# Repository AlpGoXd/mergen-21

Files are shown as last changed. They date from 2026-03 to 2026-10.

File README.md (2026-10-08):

<p align="center">
  Mergen-21 Logo
</p>

# Mergen-21: Low-Cost 21 cm Hydrogen Line Radio Telescope



A radio telescope I built for my EE401 graduation project at Ozyegin University. It listens at 1420.405 MHz (the hydrogen line), and I used it to detect hydrogen emission from the Milky Way at several pointings. Mapping its rotation is future work.

**Science goal (future work):** a Galactic rotation curve via the tangent-point method, observed from Istanbul, Turkey. The released results are first-light hydrogen-line detections with pointing dependence (south/east/west); velocity/rotation-curve analysis is not yet complete (see "Reproducing the paper" below).

---

## System Overview

RF System Block Diagram

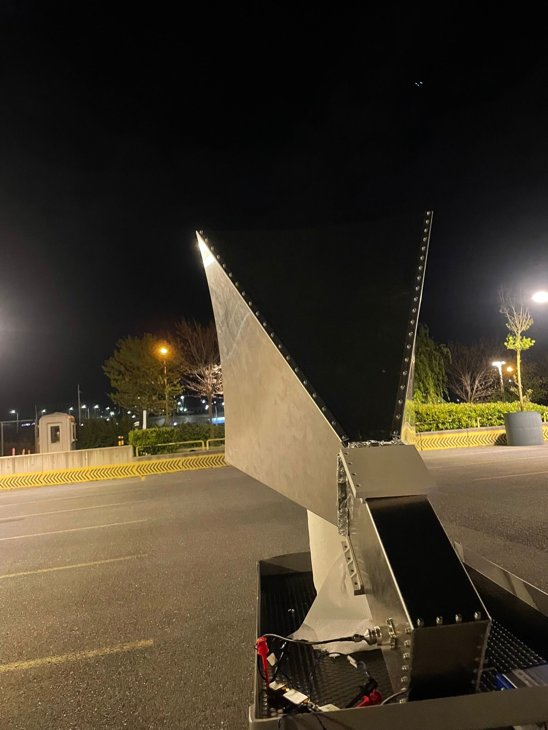
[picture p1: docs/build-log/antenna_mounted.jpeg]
Antenna mounted for first-light observations


### Antenna
- **Type:** Pyramidal horn, 1.5 mm aluminum sheet, laser-cut & bolted (M3, see ASSEMBLY.md)
- **Design frequency:** 1420.405 MHz (HI 21 cm line)
- **Measured S11:** better than −30 dB from 1410 to 1440 MHz (ZNB8, 10 MHz grid; −41.8 dB at the 1420.000 MHz sample, so the null depth is not resolved)
- **Simulated S11 (CST Studio Suite):** ideal model −19.7 dB at 1420 MHz (minimum −30.7 dB at 1396 MHz); worst-case assembly model −21.8 dB at 1420 MHz (minimum −23.1 dB at 1410 MHz)
- **Directivity:** 16.9 dBi at 1.42 GHz
- **3 dB beamwidth (simulated):** 25.2° (H-plane), 22.0° (E-plane)

### RF Chain
| Stage | Component | Function | Gain, VNA / datasheet (dB) | NF (dB) | OIP3 (dBm) |
|---|---|---|---|---|---|
| 1 | ZX60-P162LN+ | LNA | 19.24 / 19.87 | 0.7 | +29.8 |
| 2 | ZX75BP-1450-S+ | Bandpass filter (datasheet: 1 dB passband 1254–1625 MHz, 3 dB passband 1230–1645 MHz; 0.79 dB loss at 1420.4 MHz) | −1.73 / −0.79 | 0.8 | N/A |
| 3 | ZX60-V63+ | Second amplifier | 20.24 / 20.82 | 3.7 | +32.2 |
| **Cascade** | **LNA + BPF + Amp** | | **39.52 (VNA, interpolated; samples 39.66 dB at 1402.51 MHz and 39.32 dB at 1445.01 MHz)** | **1.5 (meas., cable-corrected)** | **+29.5 (meas.)** |

Gains are |S21| at 1420.405 MHz, computed by `software/analysis/stage_gains.py` (output `software/analysis/outputs/stage_gains.csv`). The measured stages sum to 37.75 dB, 1.8 dB below the measured cascade; the single-stage files are not de-embedded and the filter file includes test adapters and cables, so the cascade file is the reference for the chain gain.

### Backend
- **SDR:** ADALM-PLUTO
- **Software:** GNU Radio for signal acquisition
- **Analysis:** Python (NumPy, SciPy, Matplotlib, Astropy)

Here's what the GNU Radio receiver flowgraph looks like:

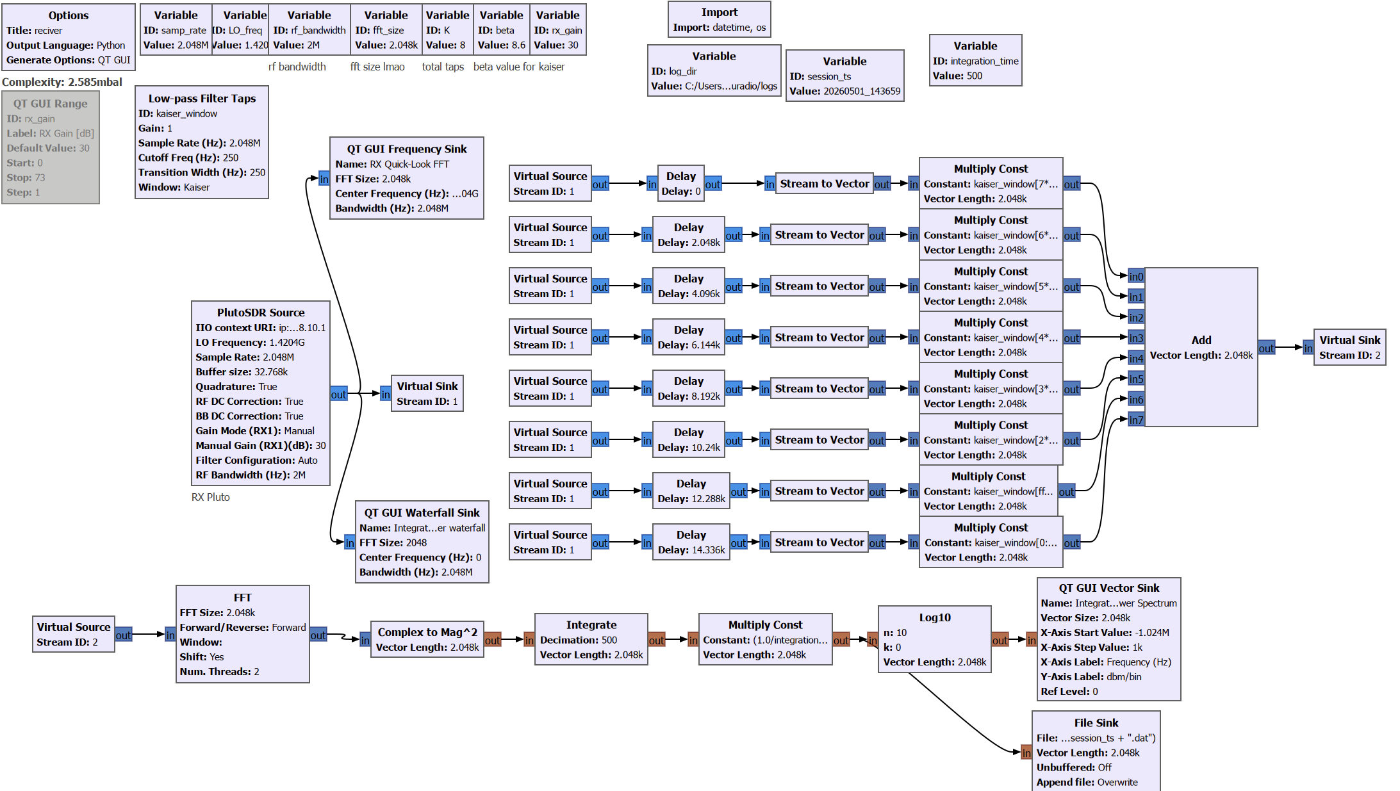
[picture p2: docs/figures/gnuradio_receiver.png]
GNU Radio receiver flowgraph


### Mechanical
- Horn antenna from laser-cut aluminum sheet metal
- Waveguide-to-coax transition with N-type connector
- A 3D-printed tripod adapter was designed (files in `hardware/antenna/3d-print/`) but the mount did not work out in practice and wasn't used for observations. While observing, the horn rested on its narrow (80 mm) wall with the N-connector axis horizontal (E-plane horizontal), not hand-held.

---

## Project Status

| Component | Status | Notes |
|---|---|---|
| Hardware (antenna, RF chain, LDO) | Complete | Fully characterized; measurement data available |
| Power supply board | Complete | Gerbers ready; BOM in `hardware/ldo-regulator/bom.pdf` |
| Simulations (CST, AWR) | Complete | Exported results in `hardware/simulation/` |
| Measurements (VNA, IP3, NF) | Complete | 39.5 +/- 0.5 dB gain, 1.5 dB NF (cable-corrected), OIP3 +29.5 dBm (cascade) |
| GNU Radio flowgraphs | Complete | `receiver.grc` (main) + `21cm synth/` test flowgraphs |
| Analysis software | Complete | `mergen21_hi_analysis.py` and `first_light_and_averaging.py` reproduce the manuscript's line fits and averaging-noise tables; see "Reproducing the paper" below and `software/analysis/outputs/VERIFICATION.md` |
| First-light observations | Complete | South/east/west pointings, 2026-04-29; data in `observations/data/`. Azimuth sweep and rotation-curve analysis are not part of the released results (see `docs/analysis/PROVENANCE_ADDENDUM.md`) |
| Open-source release | Released as v1.0-apm | Tagged release for the IEEE AP Magazine submission |

---

## Key Results

### RF Receiver
- **Cascade gain:** 39.5 dB +/- 0.5 dB (measured via ZNB8; the VNA cascade file has ~42.5 MHz point spacing and has no sample at 1420.405 MHz, the nearest points being 1402.50835 MHz and 1445.0083 MHz)
- **Cascade NF:** about 1.5 dB (1.54 dB, cable-corrected gain-method estimate: measured output noise density -133.46 dBm/Hz, +0.6 dB +/-0.2 dB estimated output-cable correction, minus the -173.9 dBm/Hz thermal floor, minus the 39.5 dB gain; add +/-0.5 dB from gain uncertainty). Friis-formula prediction: 0.81 dB with VNA stage gains (0.77 dB with datasheet gains). Design requirement: 0.96 dB.
- **Cascade OIP3:** +29.54 dBm, output-referred (−12 dBm total two-tone input, i.e. −15 dBm per tone; TOI spread 0.3 dB)
- Measurements traceable to R&S ZNB8 VNA & FSVA3044 spectrum analyzer

### Antenna
- **Measured S11:** better than −30 dB from 1410 to 1440 MHz (ZNB8, 10 MHz grid; −41.8 dB at the 1420.000 MHz sample, so the null depth is not resolved)
- **Simulated directivity:** 16.9 dBi
- **3 dB beamwidth (simulated):** 25.2° (H-plane), 22.0° (E-plane)
- Material: 1.5 mm aluminum sheet, laser-cut

---

## Repository Structure

```
mergen-21/
├── hardware/                    # All hardware (antenna, RF chain, power, sims)
│   ├── antenna/                 # Horn: CAD, drawings, DXF, STL, photos
│   ├── rf-chain/                # Component datasheets & S-parameters
│   ├── ldo-regulator/           # Dual LDO board (Altium, Gerbers, BOM, STEP)
│   └── simulation/              # CST antenna sims & AWR cascade analysis
├── measurements/                # Lab characterization data
│   ├── rf-chain/vna/            # VNA S-parameters (R&S ZNB8)
│   ├── rf-chain/ip3/            # IP3 / intermodulation
│   ├── rf-chain/nf/             # Noise figure
│   └── antenna/                 # Horn S11 & manufacturing notes
├── software/                    # Data acquisition & analysis
│   ├── gnuradio/                # GNU Radio flowgraphs (.grc) + synthesizer test flows
│   └── analysis/                # Python scripts (waterfall viewer, etc.)
├── observations/                # First-light data & plots (2026-04-29)
│   ├── data/                    # Raw spectra (.dat, NumPy float32): sample data included
│   └── plots/                   # Waterfall & sweep plots
└── docs/                        # Lab manuals, BOM, build log, diagrams
    ├── lab-manual-01-simulate.md  # Lab 1: EM sim + RF cascade analysis
    ├── lab-manual-02-build.md     # Lab 2: Fabrication & assembly
    ├── lab-manual-03-measure.md   # Lab 3: VNA, NF, IP3 characterization
    ├── lab-manual-04-observe.md   # Lab 4: GNU Radio observation & data analysis
    └── bom.md                     # Full BOM with distributor part numbers
```

## Quick Navigation

- **Try it without hardware?** → `python software/analysis/mergen21_waterfall_viewer.py` then load any `.dat` from `observations/data/`
- **Hardware files?** → [`hardware/`](hardware/): antenna CAD, RF chain, LDO, simulations
- **Measurement data?** → [`measurements/`](measurements/)
- **First-light data?** → [`observations/`](observations/): raw spectra + plots (2026-04-29)
- **Lab manuals?** → [`docs/`](docs/): four-phase curriculum (simulate, build, measure, observe)
- **BOM + costs?** → [`docs/bom.md`](docs/bom.md)
- **Running the receiver?** → [`software/gnuradio/`](software/gnuradio/): flowgraphs + setup
- **Build progress?** → [`docs/STATUS.md`](docs/STATUS.md)

---

## Quickstart: 5 minutes, no hardware required

```bash
git clone https://github.com/AlpGoXd/mergen-21.git
cd mergen-21
pip install -r software/requirements.txt
python software/analysis/mergen21_waterfall_viewer.py
```

In the viewer, click **Add...** and open any `.dat` file from `observations/data/`. Set X axis to **Velocity [km/s]** and click **Plot**. You will see two features. The narrow spike at the LO (0 kHz, 0 km/s on the velocity axis) is the band-center instrumental artifact, not hydrogen. The broad hump 80 to 190 kHz above the LO (about −16 to −36 km/s on the viewer's uncorrected topocentric axis) is the Galactic H I line.

No SDR, no antenna, no GNU Radio needed for this step. The viewer reads the recorded spectra directly.

---

## Getting Started

```bash
git clone https://github.com/AlpGoXd/mergen-21.git
cd mergen-21
pip install -r software/requirements.txt
```

**Dependencies:**
- GNU Radio 3.10+ with PlutoSDR block (gr-iio): only needed for live acquisition
- Python 3.11+: `numpy`, `scipy`, `pandas`, `matplotlib`, `astropy` (pinned in `software/requirements.txt`); the viewer also needs Tk (`python3-tk` on Debian/Ubuntu)

> CST, AWR, and Autodesk Inventor are only needed to re-run simulations or edit CAD. All exported results (S-parameters, STEP, Gerbers, PDFs) are already in the repo.

**Total system cost:** ~$413–$513 USD (see [`docs/bom.md`](docs/bom.md) for full breakdown).

---

## Observation Site

- **Location:** Istanbul, Turkey (~41.0°N, 29.0°E)
- **Target:** Galactic plane HI emission at various galactic longitudes
- **Method (future work):** tangent-point method for rotation curve extraction; not yet performed on the released data (needs frequency-axis verification, oscillator calibration, and pointing records not yet in place -- see `docs/analysis/PROVENANCE_ADDENDUM.md`)

---

## Reproducing the paper

All commands are run from the repository root, with `software/requirements.txt` installed. Each command regenerates one output; `--root` points at a checkout of this repository (defaults to the current directory) and `--outdir` selects where outputs are written.

| Command | Produces |
|---|---|
| `python software/analysis/mergen21_hi_analysis.py --root . --outdir software/analysis/outputs` | `mergen21_hi_measurements.csv` (full parameter set), `mergen21_hi_line_parameters.csv` (S/E/W summary table: peak %, FWHM, centroid, galactic l/b), `mergen21_data_manifest.csv` (sha256 of every input file), `mergen21_hi_derived.json` (scalar results quoted in the manuscript, including the noise-figure arithmetic), and `mergen21_hi_validation.png` |
| `python software/analysis/first_light_and_averaging.py --root . --outdir software/analysis/outputs` | `figures/first_light_and_averaging.pdf`/`.png` (three panels: the first-light spectra, fluctuation versus block duration, and the waterfall of the east-to-west hand sweep) and `averaging_noise.csv` (the tau=1/2/4/8 s averaging-noise table for the E1/E2 captures) |
| `python -c "from software.figures.s11_figures import fig_s11_ideal; fig_s11_ideal('hardware/simulation/cst/ideal_horn/ideal_hornfrfr.s1p')[0].savefig('s11_ideal.png')"` | The simulated horn S11 figure (1-2 GHz), marker at 1.4200 GHz |
| `python -c "from software.figures.s11_figures import fig_s11_assembly; fig_s11_assembly('hardware/simulation/cst/assembly_worstcase/hornffrfr_assembly_worstcase.s1p', 'measurements/antenna/5_inside_cleaned_backshort/anten_son_horn.s1p')[0].savefig('s11_assembly.png')"` | The CST worst-case-assembly vs. ZNB8-measured S11 overlay |
| `python -c "from software.figures.farfield_figures import fig_polar, read_cst_polar; fig_polar('hardware/simulation/cst/ideal_horn/ideal_hornfrfr_farfield_phi0.txt', None, 'H-plane', 'H-plane')[0].savefig('farfield_hplane.png')"` | An H-plane (or, with the `_phi90` file, E-plane) far-field polar cut with peak directivity, HPBW, and sidelobe callouts |
| `python software/analysis/wola_window_check.py` | The WOLA prototype-filter truncation check. Runs only with GNU Radio installed, because `wola_taps_firdes.npy` is not committed (the first run designs and caches it). GNU Radio is needed to rebuild the taps; the as-built result (824 Hz) is documented in `docs/analysis/PROVENANCE_ADDENDUM.md` |

`software/analysis/mergen21_hi_analysis.py` and `first_light_and_averaging.py` were re-run and their outputs reproduce `software/analysis/reference_outputs/` byte for byte on every platform (forward-slash manifest paths, LF line endings, and `.gitattributes` rules that keep instrument exports unconverted) -- see `software/analysis/outputs/VERIFICATION.md` for the full comparison table, including the offline-IERS caveat on galactic l/b.

**What was withdrawn, and why:** the azimuth sweep's time-to-azimuth mapping (and everything derived from it: 12 of 15 sweep-block pointings, the amplitude/centroid regressions against them, and all kelvin-scale quantities, since antenna temperature was never measured). None of these are part of the released results. Full reasoning is in [`docs/analysis/PROVENANCE_ADDENDUM.md`](docs/analysis/PROVENANCE_ADDENDUM.md); see also [`docs/analysis/MISSING_FROM_RELEASE.md`](docs/analysis/MISSING_FROM_RELEASE.md) for what a reader will not find in this release.

---

## Licensing

- **Hardware** (antenna, mechanical, RF chain): [CERN-OHL-S v2](LICENSE-HARDWARE)
- **Software** (GNU Radio, Python): [GPL-3.0](LICENSE-SOFTWARE)
- **Documentation & Photos:** [CC BY-SA 4.0](LICENSE-DOCS)
- **Data** (`observations/`, `measurements/`): [CC BY 4.0](LICENSE-DATA)

---

## Why "Mergen"?

Mergen is a figure from Turkic mythology, associated with wisdom, precision, and skilled targeting. Felt like the right name for a telescope.

## Acknowledgments

- [PICTOR project](https://github.com/0xCoto/PICTOR): reference for radio astronomy data acquisition

## Author

**Alp Gokalp**, Electrical & Electronics Engineering, Ozyegin University (Class of 2026)

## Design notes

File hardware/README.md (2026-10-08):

# Hardware

All hardware design files for the Mergen-21 21 cm radio telescope.

## Directory Structure

```
hardware/
├── antenna/            Horn antenna: CAD, drawings, DXF files, assembly photos
├── rf-chain/           RF front-end components: datasheets and S-parameter files
├── ldo-regulator/      Dual LDO power supply PCB (Altium, Gerbers, BOM, STEP)
└── simulation/
    ├── cst/            CST Studio Suite antenna EM simulations
    └── awr/            AWR Microwave Office RF cascade analysis
```

## Quick Overview

### Antenna (`antenna/`)

Pyramidal horn antenna fabricated from 1.5 mm aluminum sheet (alloy 5754-H22), laser-cut and bolted (M3, see [ASSEMBLY.md](antenna/ASSEMBLY.md)). Waveguide-to-coax transition uses an N-type connector with a copper probe.

| Subdirectory | Contents |
|---|---|
| `drawings/` | Dimensioned PDF drawings for each panel (E-plane, H-plane, backshort, waveguide) |
| `dxf/` | DXF laser-cutting files: send directly to a laser/waterjet cutter |
| `inventor/` | Autodesk Inventor parametric source files (.ipt, .iam) |
| `stl/` | STL exports of 3D-printed tripod mount parts |
| `3d-print/` | 3MF print file for the tripod adapter |
| `assembly-photos/` | Photographs from the fabrication and assembly process |
| `ASSEMBLY.md` | Step-by-step assembly instructions with photos |

Key numbers: S11 better than −30 dB from 1410 to 1440 MHz (ZNB8, 10 MHz grid; −41.8 dB at the 1420.000 MHz sample, so the null depth is not resolved); directivity 16.9 dBi (simulated).

### RF Chain (`rf-chain/`)

Three-stage front-end: LNA → bandpass filter → second amplifier. All Mini-Circuits SMA-connectorized modules.

| Stage | Component | Function |
|---|---|---|
| 1 | ZX60-P162LN+ | Low-noise amplifier |
| 2 | ZX75BP-1450-S+ | Bandpass filter (datasheet: 1 dB passband 1254–1625 MHz, 3 dB passband 1230–1645 MHz) |
| 3 | ZX60-V63+ | Second-stage amplifier |

`datasheets/` contains manufacturer PDFs. `datasheet-s-parameters/` contains Touchstone S2P files at three temperatures. See `COMPONENTS.md` for the cross-reference between datasheets, S-parameter files, and lab measurements.

### LDO Regulator (`ldo-regulator/`)

Custom dual-rail LDO PCB supplying clean DC to the two amplifiers. Two TPS7A4701RGWT ultra-low-noise LDOs. Designed in Altium Designer.

Fabrication-ready outputs: `gerbers/` (Gerber layers `PCB1_*.gbr` + NC drill file `PCB1.TXT`), `pick-and-place/` (assembly coordinates), `schematic.pdf`, `pcb.pdf`, `bom.pdf`, `PCB1.step`.

### Simulations (`simulation/`)

- `cst/`: Frequency-domain EM simulation of the horn antenna in CST Studio Suite. Includes a VBA macro (`ideal_hornfrfr_creator.mcs.bas`) that rebuilds the parametric model from scratch.
- `awr/`: Cascaded noise-figure and gain analysis of the RF chain in AWR Microwave Office. Exported results (S2P, PNG) are included so the plots can be reproduced with any S-parameter tool.

## Reproducing Designs

- **Horn antenna:** Send DXF files from `antenna/dxf/` to any laser or waterjet cutting service. Material: 1.5 mm aluminum sheet. Follow `antenna/ASSEMBLY.md`.
- **LDO PCB:** Send `ldo-regulator/gerbers/` to any PCB fabrication house. Components are listed in `ldo-regulator/bom.pdf`.
- **Simulations:** CST project can be rebuilt from the VBA macro. AWR exported S-parameter files can be re-analysed in any RF simulator or Python script.

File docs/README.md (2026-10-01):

# Documentation

Supporting documents for the Mergen-21 21 cm radio telescope project.

## Contents

| File / Folder | Description |
|---|---|
| [`bom.md`](bom.md) | Bill of materials: all components with distributor part numbers and prices |
| [`lab-manual-01-simulate.md`](lab-manual-01-simulate.md) | Lab 1: EM simulation of the horn antenna and RF cascade |
| [`lab-manual-02-build.md`](lab-manual-02-build.md) | Lab 2: Fabricating and assembling the hardware |
| [`lab-manual-03-measure.md`](lab-manual-03-measure.md) | Lab 3: VNA, noise figure, and IP3 characterization |
| [`lab-manual-04-observe.md`](lab-manual-04-observe.md) | Lab 4: First-light observation and data analysis |
| [`STATUS.md`](STATUS.md) | Subsystem completion status |
| [`build-log/`](build-log/) | Construction photographs and process notes |
| [`rf_system.drawio.svg`](rf_system.drawio.svg) | RF signal chain block diagram (editable Draw.io source in [`rf_system.drawio`](rf_system.drawio)) |

## Audience

The lab manuals are written for an instructor or student at a different institution who has no prior knowledge of this specific project. They assume access to the files in this repository but not to the original authors. Each manual can be completed independently, in order, or selectively.

## Curriculum Sequence

The four labs follow the natural project sequence:

```
Lab 1 (Simulate) → Lab 2 (Build) → Lab 3 (Measure) → Lab 4 (Observe)
```

Lab 4 can be completed without Labs 1–3 if the instructor supplies the assembled hardware or uses the included example data files.

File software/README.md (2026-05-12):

# Software

Data acquisition and analysis stack for Mergen-21.

## Structure

```
software/
├── gnuradio/       GNU Radio flowgraphs (acquisition)
├── analysis/       Python analysis scripts
└── requirements.txt
```

## Subfolders

- [`gnuradio/`](gnuradio/) — GNU Radio flowgraphs for the ADALM-PLUTO SDR
- [`analysis/`](analysis/) — Spectrum viewer, utilities, and calibration pipeline

## Viewing R&S DAT Files

`.DAT` files from the Rohde & Schwarz FSVA3044 can be opened with **[mergen-scope](https://alpgoxd.github.io/mergen-scope/)** ([GitHub](https://github.com/alpgoxd/mergen-scope)).

## Install

```bash
pip install -r requirements.txt
```

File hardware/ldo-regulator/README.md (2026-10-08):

# LDO Regulator Board

Dual LDO power supply board for the RF chain amplifiers (ZX60-P162LN+ and ZX60-V63+). Provides clean, low-noise DC rails using two TPS7A4701RGWT ultralow-noise regulators.

Designed in Altium Designer.

## Contents

| Path | Description |
|---|---|
| `altium/` | Altium Designer source files (schematic + PCB project) |
| `gerbers/` | Fabrication-ready Gerber layers (`PCB1_*.gbr`) and the Altium NC drill export `PCB1.TXT` |
| `pick-and-place/` | Assembly pick-and-place coordinates (Altium export) |
| `schematic.pdf` | Circuit schematic (PDF export) |
| `pcb.pdf` | PCB layout (PDF export) |
| `bom.pdf` | Bill of materials |
| `PCB1.step` | 3D STEP model for mechanical integration |

## Board Details

- **Regulator IC:** TPS7A4701RGWT (x2) — ultralow-noise, 1 A LDO
- **Purpose:** Supply clean DC power to RF chain amplifiers
- **Protection:** PTC fuse, LED power indicator
- **Design tool:** Altium Designer

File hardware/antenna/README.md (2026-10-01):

# Horn Antenna

Pyramidal horn antenna for 1420.405 MHz (21 cm hydrogen line), fabricated from 1.5 mm aluminum sheet (alloy 5754-H22) by laser cutting, bent and bolted (M3, see [ASSEMBLY.md](ASSEMBLY.md)).

## Directory Contents

| Path | What's in it |
|---|---|
| [`drawings/`](drawings/) | Dimensioned PDF drawings for each panel: use these as fabrication reference |
| [`dxf/`](dxf/) | DXF laser-cutting files: send these directly to a cutting service |
| [`inventor/`](inventor/) | Autodesk Inventor source files (.ipt parts, .iam assembly) |
| [`stl/`](stl/) | STL export of 3D-printed tripod mount parts |
| [`3d-print/`](3d-print/) | 3MF print file for the tripod adapter |
| [`assembly-photos/`](assembly-photos/) | Photographs from fabrication and assembly |
| [`ASSEMBLY.md`](ASSEMBLY.md) | Step-by-step assembly guide with photos |

## Key Performance (Measured)

| Parameter | Value |
|---|---|
| Measured S11 | better than −30 dB from 1410 to 1440 MHz (ZNB8, 10 MHz grid; −41.8 dB at the 1420.000 MHz sample, so the null depth is not resolved) |
| Design frequency | 1420.405 MHz (HI line) |
| Simulated directivity | 16.9 dBi |
| Simulated 3 dB beamwidth | 25.2° (H-plane), 22.0° (E-plane) |
| Material | Aluminum 5754-H22, 1.5 mm |
| Connector | N-type (Amphenol RF 000-49000-SRFX) |

## To Reproduce

1. Send the four DXF files from `dxf/` to a laser-cutting service. Specify: aluminum alloy 5754-H22, 1.5 mm thick, flatness ≤ 0.5 mm over 200 mm span.
2. Order the N-type connector (DigiKey: see `ASSEMBLY.md`).
3. Follow `ASSEMBLY.md` for assembly.
4. Verify with VNA: expected S11 < −20 dB at 1420.4 MHz.

EM simulation files are in [`../simulation/cst/`](../simulation/cst/).

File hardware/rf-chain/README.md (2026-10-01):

# RF Receive Chain

```
Antenna → ZX60-P162LN+ (LNA) → ZX75BP-1450-S+ (BPF) → ZX60-V63+ (Amp) → SDR
```

Center frequency: 1420.405 MHz | Bandpass filter (datasheet `ZX75BP-1450-S+_Plus25degC.s2p`): 1 dB passband 1254–1625 MHz, 3 dB passband 1230–1645 MHz, insertion loss 0.79 dB at 1420.4 MHz, maximum at 1435 MHz

- [`datasheets/`](datasheets/) — Manufacturer PDF datasheets for each component
- [`datasheet-s-parameters/`](datasheet-s-parameters/) — Mini-Circuits manufacturer S-parameter Touchstone files (`.s2p`) at multiple temperatures
- [`COMPONENTS.md`](COMPONENTS.md) — Cross-reference index: component → datasheet → S-parameters → measurements
- Cascade analysis results in [`../simulation/awr/`](../simulation/awr/)
- VNA measurements (measured vs. datasheet) in [`../../measurements/rf-chain/vna/`](../../measurements/rf-chain/vna/)
- IP3 / intermodulation measurements in [`../../measurements/rf-chain/ip3/`](../../measurements/rf-chain/ip3/)

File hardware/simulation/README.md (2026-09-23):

# Simulations

Computational models and exported results for the Mergen-21 antenna and RF chain.

## Subdirectories

### [`cst/`](cst/): Antenna EM Simulation

Frequency-domain EM simulation of the pyramidal horn antenna in CST Studio Suite.

Two simulation cases:
- `ideal_horn/`: Parametric model with perfect geometry. Includes a VBA macro (`ideal_hornfrfr_creator.mcs.bas`) that rebuilds the entire model from scratch in any CST installation.
- `assembly_worstcase/`: Realistic model with fabrication imperfections (panel gaps, all screws modeled) to bound the tolerance sensitivity.

Exported results: S1P (S11 reflection), STEP (3D geometry), far-field pattern text files, and PDF report.

### [`awr/`](awr/): RF Cascade Analysis

Cascaded noise-figure and gain analysis of the three-stage RF front-end in AWR Microwave Office.

Inputs: Mini-Circuits manufacturer noise-figure data for each amplifier (`.txt` files).  
Outputs: Cascaded S2P, gain plot PNG.

These results can be reproduced from the S-parameter and noise-figure files without running AWR: see `docs/lab-manual-01-simulate.md` for a Python-based approach.

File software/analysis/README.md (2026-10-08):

# Analysis

Python scripts for processing raw spectra into first-light line fits and averaging-noise statistics, plus utilities for the waterfall viewer and S-parameter cleanup. Galactic rotation curve extraction is future work, not implemented here (see "What these scripts do NOT do" below).

## Scripts

| Script | Purpose |
|---|---|
| `mergen21_hi_analysis.py` | End-to-end reproduction from the raw GNU Radio captures: `mergen21_hi_measurements.csv` (full parameter set), `mergen21_hi_line_parameters.csv` (S/E/W summary: peak %, FWHM, centroid, galactic l/b), `mergen21_data_manifest.csv` (sha256 of every input), `mergen21_hi_derived.json` (scalar results quoted in the manuscript, including the noise-figure arithmetic), and `mergen21_hi_validation.png`. Run with `--root`/`--outdir`. |
| `first_light_and_averaging.py` | Builds the three-panel first-light figure (spectra, fluctuation versus block duration, sweep waterfall) and `averaging_noise.csv` (the tau=1/2/4/8 s averaging-noise table for the E1/E2 captures) from the raw captures. Run with `--root`/`--outdir`. |
| `mergen21_waterfall_viewer.py` | Interactive waterfall / spectrum viewer for `.dat` files |
| `sanitize_sps.py` | S-parameter file cleanup utility |
| `wola_window_check.py` | Reproduces the WOLA prototype-filter truncation check. Runs only with GNU Radio installed: the designed taps (`wola_taps_firdes.npy`) are not committed, so the first run designs them with `firdes` and caches them next to the script. GNU Radio is needed to rebuild the taps; the as-built result (824 Hz) is documented in `docs/analysis/PROVENANCE_ADDENDUM.md` |

`outputs/VERIFICATION.md` records an independent re-run of `mergen21_hi_analysis.py` and `first_light_and_averaging.py` against this checkout, verified against `reference_outputs/`. See that file for the full comparison and for the offline-IERS caveat on galactic l/b.

## What these scripts do NOT do (future work)

The full calibration pipeline described in earlier drafts of this README (bandpass-ripple correction, gain calibration to K/Jy, and tangent-point rotation-curve extraction) is not implemented. What is released and verified is: line-profile Gaussian fits at 1420.405 MHz for the south/east/west pointings, and an averaging-noise (radiometer) analysis. Rotation-curve extraction needs frequency-axis verification, oscillator calibration, and pointing records not currently in this repository -- see `docs/analysis/PROVENANCE_ADDENDUM.md` for what was withdrawn from an earlier draft of this analysis and why, and `docs/analysis/MISSING_FROM_RELEASE.md` for what a reader will not find in this release.

## Quick Start

```bash
pip install -r ../requirements.txt

# Reproduce the line fits and derived scalars
python3 mergen21_hi_analysis.py --root ../.. --outdir outputs

# Reproduce the first-light figure and averaging-noise table
python3 first_light_and_averaging.py --root ../.. --outdir outputs

# View a spectrum interactively
python3 mergen21_waterfall_viewer.py ../../observations/data/
```

## Calibration Reference

- **Cascade gain:** 39.5 dB +/- 0.5 dB (measured; the VNA cascade file has ~42.5 MHz point spacing and no sample exactly at 1420.405 MHz)
- **System NF:** about 1.5 dB (1.54 dB, cable-corrected gain-method estimate; see `measurements/rf-chain/nf/README.md`)
- **BPF ripple:** ±0.5 dB across 1400–1500 MHz (not yet corrected for in the released analysis scripts)

```python
import numpy as np

rows = np.fromfile(path, dtype=np.float32).reshape(-1, 2048)  # linear power, one row per saved average; channel k is (k - 1024) kHz from the LO
```

## See Also

- Observation data: [`../../observations/`](../../observations/)
- GNU Radio flowgraphs: [`../gnuradio/`](../gnuradio/)
- Simulation reference: [`../../hardware/simulation/`](../../hardware/simulation/)

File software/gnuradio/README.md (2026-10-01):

# GNU Radio Flowgraphs

Real-time signal acquisition and synthesis flowgraphs for the ADALM-PLUTO SDR, targeting 1420.405 MHz hydrogen line observations.

## Flowgraphs

### Receiver

| File | Purpose | Input | Output |
|---|---|---|---|
| `receiver.grc` / `receiver.py` | Main HI line receiver | PlutoSDR I/Q | Spectrum data (`.dat`) |

### Synthesis / Test (`21cm synth/`)

Test flowgraphs used to validate the analysis pipeline without live RF hardware:

| File | Purpose |
|---|---|
| `topo1_cw_tone.grc` | Single CW tone at 1420.405 MHz |
| `topo2_single_gaussian.grc` | Gaussian spectral line (simulated HI) |
| `topo3_galaxy_rotation.grc` | Multi-component Gaussian (simulated galactic HI spectrum) |
| `topo3_required_constants.grc` | Physical constants block used by topo3 |
| `fftdemo.grc` | Basic FFT display demo |
| `testingit.grc` | Scratch/test flowgraph |

## Hardware Setup

**Expected signal path:**
```
Antenna (16.9 dBi) → LNA (19.24 dB) → BPF (−1.73 dB) → Amp (20.24 dB) → PlutoSDR   [VNA, 1420.405 MHz]
Cascade: 39.52 dB gain (VNA), ~1.5 dB NF (cable-corrected)
```

**PlutoSDR settings (receiver):**
- Center frequency: 1420.405 MHz
- Sample rate: 2.048 MS/s (2.048 MHz complex span, 1 kHz channels with fft_size = 2048)
- RF bandwidth: 2 MHz (`rf_bandwidth = 2000000`)
- PlutoSDR gain: 30 dB, manual (`rx_gain = 30`)
- Device URI: `ip:192.168.10.1` (a stock Pluto on USB is `ip:192.168.2.1`; change `uri` in the Pluto source block)

## Installation

```bash
# Ubuntu 22.04
sudo apt install -y gnuradio gr-iio

# Or conda (more reliable)
conda create -n gnuradio -c conda-forge gnuradio=3.10 gr-iio
conda activate gnuradio
```

## Running

```bash
# GUI
gnuradio-companion receiver.grc

# Headless
python3 receiver.py
```

## Observation Workflow

1. Connect antenna → LNA power supply → PlutoSDR → PC
2. Verify PlutoSDR: `usb-devices | grep 0456`
3. Launch `receiver.grc` in GRC
4. Set center frequency to 1420.405 MHz, confirm sample rate 2.048 MS/s
5. Create the output directory (`mkdir -p logs`; the file sink does not create it), then run; output is written to `logs/` relative to the working directory

## Output Format

The receiver saves NumPy float32 power spectra (not raw I/Q) to `logs/` (relative to the working directory). The released files were then copied to `observations/data/`:

```python
import numpy as np
spec = np.fromfile('../../observations/data/mergen21_spec_20260429_041703.dat', dtype=np.float32)
```

## Troubleshooting

**PlutoSDR not detected:**
```bash
usb-devices | grep 0456
# Try: sudo, USB 2.0 port, reseat cable
```

**gr-iio not found:**
```bash
conda install -c conda-forge gr-iio
```

**Flowgraph freezes:**
- Reduce sample rate to 1 MSPS
- Check USB bandwidth (`dmesg`)

**Flat / noisy spectrum:**
- Verify LDO power supply (+4 V LNA and +5 V amplifier rails)
- Check SMA connections

## Simulated HI-Line Injector

`receiver.grc` also contains a simulated hydrogen-line transmit chain (`tx_noise` -> `tx_lpf` -> `tx_rotator` -> `iio_pluto_sink_0`) used to inject a synthetic Gaussian line for pipeline testing. All four blocks are saved with `state: disabled` in the flowgraph. The RX Pluto (`pluto_rx`, `uri: ip:192.168.10.1`) and the TX Pluto (`iio_pluto_sink_0`, `uri: ip:192.168.20.1`) are configured with different device URIs, so this is a loopback/self-test path that requires a second physical PlutoSDR; it is not a path that could inject into a live RX capture through the same device. This does not by itself establish whether the injector was disabled during any particular observing session.

The injector is a self-test path that needs a second PlutoSDR; the first-light build had one PlutoSDR, so the injector was not active during the 2026-04-29 captures.

## Known issue: truncated WOLA prototype filter

The flowgraph builds an 8-branch WOLA/PFB channelizer. The prototype filter is designed with:

```
firdes.low_pass(1.0, samp_rate, samp_rate/(4*fft_size), samp_rate/(4*fft_size), window.WIN_KAISER, beta)
```

with `samp_rate = 2048000`, `fft_size = 2048`, `beta = 8.6`. This call returns 32,299 taps in total. However, the 8 channelizer branches (the `blocks_multiply_const_vxx_*` blocks) only consume `kaiser_window[0:8*fft_size]`, i.e. the first 16,384 taps. The effective analysis window used by the channelizer is therefore truncated well before the filter's natural end, cutting it off just past its peak rather than using the full symmetric taper.

A reproducible check for this (32,299 designed vs. 16,384 used) is at `software/analysis/wola_window_check.py`. As of this writing, `software/analysis/wola_taps_firdes.npy` (the committed reference taps needed by that script) had not yet been added to the repository, so verifying the tap counts numerically requires a working GNU Radio 3.10 installation to regenerate the taps; if `wola_taps_firdes.npy` has since been committed, `wola_window_check.py` can be run directly without GNU Radio.

## See Also

- [GNU Radio docs](https://www.gnuradio.org/)
- [ADALM-PLUTO quick start](https://wiki.analog.com/university/tools/pluto)
- [gr-iio](https://github.com/analogdevicesinc/gr-iio)
- Analysis pipeline: [`../analysis/`](../analysis/)
- Waterfall viewer: [`../analysis/mergen21_waterfall_viewer.py`](../analysis/mergen21_waterfall_viewer.py)
- Observation data: [`../../observations/`](../../observations/)

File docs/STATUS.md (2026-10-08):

# Repository Status Matrix

High-level status snapshot for major subsystems.

Last updated: 2026-09-23

| Area | Status | Notes |
|---|---|---|
| Hardware (antenna, RF chain, LDO, simulations) | Complete | All under `hardware/`; fully characterized and documented. |
| Measurements (VNA, IP3, NF, antenna) | Complete | All under `measurements/`. |
| Build log | Complete | Photos in `docs/build-log/`; assembly notes in `hardware/antenna/ASSEMBLY.md`. |
| GNU Radio software | Complete | `receiver.grc` (main acquisition) + `21cm synth/` test flowgraphs in `software/gnuradio/`. |
| Analysis software | Complete for first-light; K/Jy calibration and rotation-curve extraction not started | `mergen21_hi_analysis.py` and `first_light_and_averaging.py` reproduce the manuscript's line fits, galactic l/b, and averaging-noise tables (see `software/analysis/outputs/VERIFICATION.md`). Waterfall viewer also in `software/analysis/`. |
| First-light observations | Complete for south/east/west pointings; azimuth sweep withdrawn | Raw spectra in `observations/data/`. The manual azimuth sweep's pointing cannot be recovered and is not part of the released results; see `docs/analysis/PROVENANCE_ADDENDUM.md`. |
| Rotation curve (tangent-point method) | Not started | Future work; needs frequency-axis verification, oscillator calibration, and pointing records not yet in place. |
| Open-source release prep | Released as v1.0-apm | Tagged release for the IEEE AP Magazine submission. |

## Notes

- This matrix is intentionally simple and is the single source of truth for completion status.
- For subsystem details, follow each folder README.

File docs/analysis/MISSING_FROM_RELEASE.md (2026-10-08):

# Missing from release: items the paper mentions but this audit could not find

This document reports, for each item below, whether it was found in the repository and at
what path, or whether it is absent. Nothing here is fabricated or reconstructed; each entry
reflects what was actually present in the working tree at the time of this audit
(2026-09-23, branch `paper-release`).

## 1. 50 ohm-terminated SDR capture (band-center artifact): now included

The paper's discussion of the band-center instrumental artifact (see
`software/analysis/mergen21_hi_analysis.py` line ~132, `first_light_and_averaging.py`
line ~83, and `docs/analysis/archive/mergen21_hi_methods_superseded.md` lines ~17-55, archived) refers to an artifact
that appears in the SDR power-spectrum output near band center.

- **Now included:** `observations/data/band_center_tests/` (re-measured 2026-10-08, Pluto input terminated
  in 50 ohms at three LO settings; see its README). The April sky files under `observations/data/` remain
  sky pointings.
- **Found, but a different measurement:** `measurements/extras/50ohm-match/` contains
  `MCL ANNE-50+.s1p` (a VNA S11 measurement of the 50 ohm matched load itself, i.e. how well
  it is matched) and `50-match.pdf`. This is a VNA characterization of the termination
  component, not an SDR power-spectrum capture, and it does not show the band-center
  artifact. Do not conflate the two: the matched-load S11 measurement exists; the SDR
  capture with that load on the Pluto input does not appear to be in the repository.

## 2. "Receiver connected vs. SDR input terminated" comparison spectra (0.056 dB SDR NF)

Searched the whole repository (all file types, filenames and content) for any reference to
an SDR-stage noise figure of about 0.056 dB, or to a paired comparison of "receiver
connected" vs. "SDR input terminated" spectra.

- The original receiver-connected comparison was not archived, and the receiver chain is no longer available. The SDR noise contribution is instead bounded by comparing the Pluto-terminated capture with the first-light sky records (same Pluto, gain and flowgraph): the SDR raises the system noise by about 4 % (0.18 dB). See `observations/data/band_center_tests/README.md`.

## 3. Output-cable loss file

- **`measurements/rf-chain/nf/cable_loss.DAT`: found.** Present alongside
  `cable_loss.PNG` in `measurements/rf-chain/nf/`. This is the file
  `software/analysis/mergen21_hi_analysis.py` (`CABLE_LOSS_DB = 0.6`, line ~94) references
  by path (`measurements/rf-chain/nf/cable_loss.DAT`).
- **`measurements/rf-chain/ip3/cable-loss/cable_loss_100kHz.DAT`: found**, alongside
  `cable_loss_100kHz.PNG`, at `measurements/rf-chain/ip3/cable-loss/`. This is a separate
  cable-loss measurement associated with the IP3 test setup (per
  `measurements/rf-chain/nf/README.md`'s "See Also" section, the IP3 and NF measurements
  share the same cable-loss reference value). It is not the file the analysis script reads;
  the script reads `nf/cable_loss.DAT` only.

## 4. Probe-trimming S11 sequence (antenna build, Section 2)

`measurements/antenna/` contains exactly five numbered milestone entries, as expected:

1. `1_outside_uncalibrated/alp_anten_uncal_0.s1p`
2. `2_outside_calibrated/alp_anten_cal_0.s1p`
3. `3_inside_calibrated/alp_anten_lab_0.s1p`
4. `4_inside_aluminum_foil/alp_anten_lab_0_enhanced.s1p` (renamed from the doubled
   `.s1p.s1p` extension in this same change set; see the "Fix doubled .s1p extension"
   commit)
5. `5_inside_cleaned_backshort/anten_son_horn.s1p` (the final, "definitive" state)

Plus a non-numbered `README.md` and an `antenna_photos/` subfolder. No finer-grained
intermediate probe-trimming cuts (e.g., per-millimeter probe depth steps) were found beyond
these five milestones; the milestone sequence is the complete measurement record present in
the repository.

## 5. CST project files

- **No `.cst` project file found** anywhere under `hardware/simulation/cst/` (or
  elsewhere in the repository). That directory contains only:
  - `assembly_worstcase/hornffrfr_assembly_worstcase.stp` (STEP geometry) plus
    `hornffrfr_assembly_worstcase_phi0.txt` / `_phi90.txt` (far-field cuts)
  - `ideal_horn/` with `ideal_hornfrfr_all_parameters.txt`,
    `ideal_hornfrfr_farfield_phi0.txt`, `ideal_hornfrfr_farfield_phi90.txt`
  - a `README.md`
  - (per the directory's own README, also an `.mcs.bas` macro and PDF reports are part of
    the intended content set; this audit did not re-verify every file, only confirmed the
    absence of any `.cst`)
- **Relevant context:** the repository's `.gitignore` already excludes `*.cst` and `*.awr`
  (lines 125-126), and `*.awr.bak` (line 61). Even if a `.cst` project file existed locally
  on the author's machine, it would not be trackable in this repository without an explicit
  `git add -f` or a `.gitignore` exception, so its absence here is expected regardless of
  whether one exists in the author's local CST workspace.

## 6. Far-field exports for Fig. 2(b,c) and TikZ polar figures

- **Raw numeric far-field `.txt` cuts: found**, under `hardware/simulation/cst/`:
  - `assembly_worstcase/hornffrfr_assembly_worstcase_phi0.txt` and `_phi90.txt`
  - `ideal_horn/ideal_hornfrfr_farfield_phi0.txt` and `_phi90.txt`
  - This audit did not verify the exact point count (360 points/cut) of each file; that
    would require parsing the files, which was out of scope for this presence/absence
    survey.
- **Rendered figure sources: found**, in `software/figures/` (added by a parallel agent
  working in that directory; present as of this audit):
  - `software/figures/s11_figures.py` and `software/figures/farfield_figures.py`
    (matplotlib figure generators)
  - `software/figures/tikz/` with `fig1_s11_ideal.tex`, `fig2_s11_assembly.tex`,
    `fig3_farfield_eplane.tex`, `fig4_farfield_hplane.tex`, and
    `software/figures/tikz/data/` containing `ff_eplane.dat`, `ff_hplane.dat`,
    `s11_assembly_cst.dat`, `s11_ideal.dat`, `s11_measured.dat`.
  - This audit did not check these files' content for correctness or completeness, only
    their presence, since another agent owns `software/figures/`.

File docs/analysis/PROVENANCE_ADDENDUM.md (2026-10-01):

# Provenance addendum

Issued in response to the observer's finding that the azimuth sweep was
manual, irregular in azimuth and included pauses, that elevation was held
only approximately fixed, and that antenna temperature was never measured.

This addendum supersedes the affected parts of the earlier provenance and
methods notes (the methods document is archived as
`archive/mergen21_hi_methods_superseded.md`). The manuscript has not been
touched.

**The outputs generated before this addendum are superseded**: those
computed with the 0.5 s row cadence, the sweep-azimuth regressions and
latitude correlation, and the kelvin sensitivities. Nothing from them should
be quoted. The current `software/analysis/outputs/` were regenerated after
these corrections (1.0 s rows; the sweep regressions are listed under
`withdrawn` in `mergen21_hi_derived.json`); see
`software/analysis/outputs/VERIFICATION.md`. Their `dT_*_K_assumed_Tsys`
fields still rest on an assumed system temperature and should not be quoted
either.

---

## 1. Withdrawn

| withdrawn | reason |
|---|---|
| the linear time-to-azimuth mapping across the sweep | the sweep was manual and irregular with pauses, so elapsed time does not map to azimuth |
| azimuth, and therefore *l* and *b*, for all 12 sweep blocks | derived from that mapping |
| predicted radial velocity for all 12 sweep blocks | derived from that mapping |
| the 15-point regression of centroid against predicted motion, and its slope 2.63 +/- 0.32 | 12 of its 15 points are withdrawn |
| the 3.8 sigma exclusion of a fixed terrestrial frequency | same regression |
| the correlation of amplitude against \|b\|, r = -0.70 | 12 of its 15 points are withdrawn |
| every quantity in kelvin | T_sys was never measured; see section 2 |
| elevation 35 degrees as a fixed value (now 30°, observer-stated) | held only approximately, and never instrumented |

Panels (b) and (c) of the figure lose 12 of their 15 points. Three points do
not support a regression, a correlation coefficient, or a significance.

## 2. Antenna temperature was not measured

The analysis converted fractional quantities to kelvin using a single
constant, `T_SYS_K = 193.5`, formed from an assumed antenna temperature plus
a receiver temperature derived from the noise figure. The antenna
contribution was never measured, so every kelvin value in the package is
fractional data multiplied by an assumed scale factor.

**What survives:** all fractional quantities, which is what the instrument
actually measures. Line amplitude as a percentage of continuum, fractional
rms, and the ratio of the two are unaffected. The sensitivity discussion
should be conducted in fractional units, or in kelvin only with the
assumed scale stated at every occurrence.

The noise consistency test in section 5 is therefore formulated so that
T_sys cancels.

## 3. Which east capture

**`mergen21_spec_20260429_050204_doggu.dat`**, 104 rows, started 05:02:04
local. Confirmed by re-measuring both candidates and comparing against the
exported table:

| | rows | fitted amplitude | raw peak | centroid | FWHM |
|---|---|---|---|---|---|
| exported table, row E | 104 | 7.868 % | 12.281 % | | 88.89 kHz |
| `..._050204_doggu.dat` | 104 | 7.868 % | 12.225 % | 138.48 +/- 0.50 kHz | 88.89 kHz |
| `..._050450_Dogu_100.dat` | 171 | 6.930 % | 13.667 % | 117.94 +/- 1.53 kHz | 93.43 kHz |

The amplitude and FWHM match to all quoted digits, so the identification is
certain.

**A second east capture exists and was never used.** `Dogu_100` was recorded
166 s later at the same nominal pointing. Its centroid sits 20.5 kHz below
the used capture, a difference of 12.7 combined standard errors, equivalent
to 4.3 km/s. This is an unused repeat observation that disagrees with the
one that was reported by far more than its formal uncertainty. It bears
directly on how reproducible a single pointing's centroid is, and it should
be reckoned with before any centroid-based claim is rebuilt.

## 4. Acquisition settings: confirmed by the observer; the flowgraph does not describe them

**The observer confirmed these settings on 2026-09-13.** West, south, the
05:02:04 east capture and the sweep all used `integration_time = 1000`. Only
the 05:04:50 east capture used 100. The frame period is
`FFT_SIZE / SAMP_RATE = 1.000 ms` exactly, so `tau_row = N_int / 1000` s.

| capture | setting | tau_row | rows | duration | source |
|---|---|---|---|---|---|
| `..._045525_bati.dat` (west) | 1000 | 1.0 s | 106 | 106.0 s | observer |
| `..._045857_guney.dat` (south) | 1000 | 1.0 s | 103 | 103.0 s | observer |
| `..._050204_doggu.dat` (east) | 1000 | 1.0 s | 104 | 104.0 s | observer |
| `..._050450_Dogu_100.dat` (east repeat) | 100 | 0.1 s | 171 | 17.1 s | observer, filename agrees |
| `..._050554_180partygirl_500int.dat` (sweep) | 1000 | 1.0 s | 293 | 293.0 s | observer; **filename disagrees** |

Every nominal duration is shorter than the gap to the next capture's start
time, which is a necessary consistency check and it passes for all five.

**Two written records contradict the observer, and neither is used.**
`software/gnuradio/receiver.grc` carried `integration_time = 500`, which matches no
capture in this package; the flowgraph was saved at the end of the session,
after the setting had last been changed. The `500int` in the sweep filename
likewise does not record that capture's setting. The observer states the
filename is misleading. Both disagreements are recorded here rather than
resolved silently, because a reader who opens the flowgraph will otherwise
find a number that matches nothing.

**What the previous revision inferred, and where it was wrong.** That
revision derived the cadence from per-row noise, calibrating `N_eff` against
the two captures whose filenames state a setting. It got the three static
captures right at 1000 and the sweep wrong at 500. The failure mode is now
identified. `N_eff` measured by differencing successive rows assumes the sky
is unchanged between them; the sweep was in manual motion, so consecutive
rows differ by real sky change as well as by noise, which inflates the
measured sigma and deflates the apparent `N_eff`. The sweep's apparent
`N_eff` of 366 is an artifact of pointing motion, not a record of its
cadence. **Row-differenced noise cannot be used to infer cadence on a moving
pointing**, and the previous revision did not carry that caveat.

A second, smaller leak affects the stationary captures. Receiver level swings
by 10 to 17 percent within a capture, and a plain row difference carries that
gain fluctuation into the noise estimate. Normalising each row by its own
mean level before differencing removes it and brings all four stationary
captures into agreement:

| capture | plain differencing | gain-normalised | `N_eff` | `B_eff` | level swing |
|---|---|---|---|---|---|
| west | 3.792 % | 3.493 % | 819.7 | 819.7 Hz | 16.6 % |
| south | 3.533 % | 3.489 % | 821.3 | 821.3 Hz | 13.3 % |
| east | 3.519 % | 3.500 % | 816.5 | 816.5 Hz | 10.3 % |
| east repeat | 11.080 % | 11.077 % | 81.5 | 814.9 Hz | 13.8 % |
| sweep (moving; excluded) | 5.228 % | 4.946 % | 408.8 | not estimable | 37.2 % |

The four stationary captures now agree on `B_eff` to 0.8 percent, where plain
differencing spread them over 17 percent. West was the worst affected and is
no longer an outlier.

**Consequence for the package.** The three static on-source times are
unchanged at 106, 103 and 104 s. The sweep's total duration is **293 s, not
the 146.5 s** the previous revision's 0.5 s cadence implied, and each sweep
block is 24 to 25 s rather than 12 to 12.5 s. No reported quantity depends on
the sweep's duration, since the sweep is retained only as a descriptive
time-frequency observation, but the table and figure now carry the correct
value. `analysis/mergen21_hi_analysis.py` no longer holds a single cadence
constant; it carries `INTEGRATION_FRAMES` per file, and
`analysis/outputs/mergen21_capture_metadata.csv` records the setting, the
derived cadence and the provenance of each alongside.

## 5. Exact filter and averaging implementation

Both `software/gnuradio/receiver.grc` and the generated `software/gnuradio/receiver.py`
are in this package. The signal path is:

```
Pluto source (LO 1 420 405 000 Hz, 2.048 MSa/s, 2 MHz BW, 30 dB manual gain)
  -> 8 parallel branches k = 0..7:
       delay(k * 2048 complex samples)
       stream_to_vector(2048)
       multiply_const_vcc(kaiser_window[k*2048 : (k+1)*2048])
  -> add_xx (sums the 8 windowed segments)
  -> fft_vcc(2048, forward=True, window=[], shift=True, nthreads=2)
  -> complex_to_mag_squared(2048)
  -> integrate_ff(integration_time, 2048)
  -> multiply_const_vff(1.0 / integration_time)
  -> file_sink(float32 * 2048)
```

This is a weighted overlap-add filterbank with K = 8 branches, M = 2048
channels, a hop of 2048 samples, and therefore a window length of 16384
samples with eightfold overlap. The frame rate is 1000 per second. The FFT
runs with `shift=True`, which is why the stored rows are DC-centred. The
file sink is fed from the integrator through the 1/`integration_time`
scaling, so the stored values are **linear mean power**; the `nlog10` block
in the graph drives only the on-screen display. All four transmit blocks are
`state: disabled`.

### Prototype filter length: settled, and the truncation is real

GNU Radio is now installed, so the call was run rather than reconstructed:

```python
kaiser_window = firdes.low_pass(1.0, samp_rate, samp_rate/(4*fft_size),
                                samp_rate/(4*fft_size), window.WIN_KAISER, beta)
# = firdes.low_pass(1.0, 2048000, 250.0, 250.0, WIN_KAISER, 8.6)
```

It returns **32 299 taps**, confirming the `firdes::compute_ntaps` rule
(32 299) and refuting the `scipy.signal.kaiserord` rule (44 958). The
prototype peaks at tap **16 149**.

The eight branches consume `kaiser_window[0 : 8*2048]`, that is taps 0 to
16 383. So the cut falls **235 taps past the peak, at 99.4 percent of peak
height**, and **15 915 taps, 49 percent of the designed filter, are never
referenced by any block.** The intended symmetric taper has its entire
falling half discarded; what the filterbank actually applies is the rising
edge chopped off just after its maximum.

The delay-to-slice pairing was read from the flowgraph connections rather
than assumed: branch `delay = k*fft_size` receives
`kaiser_window[(7-k)*fft_size : (8-k)*fft_size]`, so the effective window is
exactly `taps[0:16384]` applied to one contiguous 16 384-sample span. The
chain is a textbook WOLA: eight delayed branches, `stream_to_vector`,
per-branch multiply, an 8-input adder, one `fft_size` FFT with `shift: True`,
magnitude-squared, `integrate` by `integration_time`, then a
`1/integration_time` scale (so rows are means, not sums).

**This confirms the claim that the previous revision of this section
retracted.** The retraction was wrong, and it was my error, not the data's:
my predicted `N_eff` for the truncated candidate (97.4) was computed
incorrectly, and so was the one for the complete taper (75.0). Simulating
white noise through the chain reconstructed above -- with frames hopping by
`fft_size` while spanning `8*fft_size`, so consecutive frames share seven
eighths of their samples -- gives:

| candidate window | `N_eff` at N_int = 100 | `B_eff` | lag-1 corr. |
|---|---|---|---|
| **measured (`Dogu_100`)** | **81.5** | **815 Hz** | **+0.051** |
| as built: first 16 384 of 32 299 | 82.4 | 824 Hz | +0.085 |
| complete symmetric 16 384-tap taper | 53.6 | 536 Hz | +0.023 |

`N_eff` is the discriminating statistic and it is decisive: the as-built
window predicts 82.4 against 81.5 measured, a one percent agreement, while a
correct taper predicts 53.6 and is wrong by 34 percent. `B_eff` agrees to 1.1
percent, now that the cadence entering the measured value is
observer-confirmed rather than inferred. The lag-1 channel correlation does **not** discriminate at this
precision -- its standard error is about 0.04 over 600 realisations, so the
+0.085 and +0.023 predicted for the two candidates are less than two standard
errors apart -- but the as-built value does
independently reproduce, from first principles, the +0.043 to
+0.050 measured on the real captures and quoted in the superseded methods document.

**What it costs the instrument.** The truncation is a genuine defect and may
be described as one in print, but its cost is spectral purity, not
sensitivity:

* Adjacent-channel rejection collapses from -95.6 dB to **-16.7 dB**. A
  monochromatic signal spills about 2 percent of its power into each
  neighbouring channel and 0.5 percent into the next one out. This bears
  directly on the narrowband spur at +406 kHz baseband, which reaches 12
  percent of continuum in the east pointing: it contaminates its neighbours
  at the few-tenths-of-a-percent level, and any narrow feature in these
  spectra is broader than the instrument's designed channel response.
* It does **not** measurably broaden the H I line. The leakage spans a few
  1 kHz channels against a fitted line width of 77 to 152 kHz.
* Sensitivity is not degraded. `B_eff` is 824 Hz as built against 536 Hz for
  a correct taper, so the radiometric noise per unit integration time is
  slightly *lower* than a correct implementation would deliver. No
  sensitivity figure in the manuscript is invalidated by this.
* The fix is one line: design the prototype to exactly `K*fft_size` taps, or
  pass the tap count explicitly, rather than letting `firdes` choose a length
  from the attenuation and transition width.

A two-panel truncation figure (not included in this release) showed the
designed prototype with the consumed and discarded spans, and the resulting
channel-leakage penalty against a correct taper. The whole check is
reproducible by `python software/analysis/wola_window_check.py`, which needs
GNU Radio on its first run to design the 32 299 taps (the cached
`wola_taps_firdes.npy` is not committed); Monte Carlo figures quoted above are that script's output and
carry a few percent of run-to-run scatter.

### Effective channel bandwidth: confirmed at 818 Hz

**This section was withdrawn two revisions ago, restored at 753 Hz in the
previous revision, and is now confirmed at 818 Hz.** The withdrawal argued
that reading `B_eff` from the measured `N_eff` assumes the row is an average
of `B_eff * tau_row` independent samples, which the overlap between the eight
hops violates. That objection was misdirected on two counts. First,
`B_eff = N_eff / tau_row` is a definition of effective noise bandwidth, not
an independence assumption; the physical content sits entirely in whether the
measured `N_eff` matches what the window and the frame overlap predict.
Second, the simulation in the previous subsection models that overlap
explicitly, so a prediction is available.

The measurement has since improved twice: the cadence is observer-confirmed
rather than inferred to 10 percent, and gain-normalised differencing removes
the receiver level drift described in section 4.

| | `B_eff` |
|---|---|
| **measured, four stationary captures** | **818.1 +- 2.9 Hz** |
| simulated, window as built | 824 Hz |
| simulated, complete taper (counterfactual) | 536 Hz |
| channel spacing, for reference | 1000 Hz |

Measurement and simulation now agree to **0.7 percent**, against 9 percent in
the previous revision, and the four captures agree among themselves to 0.8
percent. The counterfactual complete taper is off by 35 percent. **This is
the strongest available confirmation that the analysis window is truncated as
section 5 describes**, and it is independent of the tap-count argument: it
uses only the measured noise of four captures and a simulation of the
as-built chain.

Two consequences for the manuscript. The effective channel bandwidth is
narrower than the 1000 Hz channel spacing, by 18 percent rather than the 25
percent the previous revision reported. And substituting 818 Hz for the
previous 753 Hz lowers a radiometer-predicted channel sensitivity by 4.1
percent, since `dT` scales as `1/sqrt(B)`, moving the prediction toward the
measured value rather than away from it.

### Noise consistency, without any assumed quantity

The earlier radiometer test compared measured fractional noise against
`1 / sqrt(B_eff * tau)`. Because `B_eff` had itself been fitted from the same
noise data, that test was close to circular, and its claim to be
"independent corroboration" of the cadence is withdrawn.

The test below replaces it and assumes nothing at all. If the rows of a
capture are independent, the noise in the averaged spectrum must be the
per-row noise divided by the square root of the number of rows. Both sides
are measured on the same line-free channels of the same file. No system
temperature, no channel bandwidth, no cadence enters:

| pointing | rows | per-row fractional rms | predicted | measured | ratio |
|---|---|---|---|---|---|
| west | 106 | 0.0379 | 0.003683 | 0.003349 | 0.91 |
| south | 103 | 0.0353 | 0.003481 | 0.003276 | 0.94 |
| east | 104 | 0.0352 | 0.003450 | 0.003240 | 0.94 |

The averaged spectra are 6 to 9 percent quieter than independent rows
predict. That is a small residual in the safe direction for a detection
claim, and it is consistent with the successive-difference estimator
slightly overstating per-row noise. **The 23 percent shortfall flagged as
unresolved in the superseded methods document was an artifact of the assumed 1000 Hz bandwidth
and 0.5 s cadence, not a property of the data.** It does not survive a test
that makes no such assumptions, and it is closed on that basis rather than
by the bandwidth correction previously claimed.

### What the cadence inference rested on, and why it is superseded

The previous revision calibrated `N_eff` against the two captures whose
filenames state a setting, and concluded `tau_row ~ 1.0 s` for the static
pointings from two anchors agreeing to 10 percent. That reasoning is now
superseded by the observer's confirmation, and section 4 records where it
failed: one of its two anchors, the `500int` filename, does not record its
capture's setting at all. The inference reached the right answer for the
three static captures for partly wrong reasons, and the wrong answer for the
sweep. It is retained here as a worked example of what noise statistics can
and cannot settle without a session record.

## 6. The rebuilt figure and table

The pipeline was rerun with the withdrawn geometry removed, the cadence
corrected to the observer-confirmed per-file integration settings, and every kelvin quantity flagged as resting on an assumed
`T_sys`. Two of the three figure panels had to be replaced, because both of
them took sweep azimuth as an input.

| Panel | Was | Is now |
|---|---|---|
| (a) | three averaged spectra, labelled by Galactic latitude | unchanged, but labelled by azimuth: the latitude of a static pointing depends on an elevation the observer held only approximately |
| (b) | fitted centroid against predicted observer motion, 15 points | measured noise in the averaged spectrum against the noise predicted from its own rows |
| (c) | fitted amplitude against \|b\|, Pearson r | fitted centroid against fitted amplitude, with the scatter of all 15 |

Panel (b) is the replacement worth keeping regardless of whether the pointing
is ever recovered: neither of its axes uses `T_sys`, channel bandwidth, or
row cadence. It compares the noise measured in each averaged spectrum against
`sigma_row / sqrt(n_rows)` measured from the same capture's own rows. All 15
measurements land between 0.85 and 1.00 of that prediction, mean 0.92. The
averaged spectra are therefore integrating down as independent samples would,
slightly better than the row estimator predicts; that estimator is itself
differenced, which biases it marginally high.

### The centroid scatters far more than the fits admit

This is new, and it bears on the manuscript. Across the 15 measurements the
fitted line centroid spans 75 to 180 kHz, standard deviation 34 kHz. The
formal fit errors are 0.5 to 2.9 kHz for the 14 well-detected measurements,
median 0.8 kHz. The scatter is therefore roughly 40 times the formal error.

Two consequences:

* **No centroid uncertainty derived from a single fit should be quoted.** The
  fit error describes how well a Gaussian localizes a fixed line shape in
  noise. It does not describe how much the answer moves between
  measurements, which is the quantity a reader needs. If a centroid is
  quoted, the uncertainty should be the scatter across repeats.
* It is the same effect seen in section 3, where the two east captures taken
  four minutes apart gave centroids differing by far more than either fit
  error. That disagreement is not anomalous; it is this scatter.

The cause is not established. Real structure along different sight lines
would produce it, and so would a pointing that drifted, and so would
baseline-fit sensitivity in the low-amplitude captures. With the sweep
azimuths withdrawn there is no direction to correlate it against, so it
cannot be separated here.

### West is not line-free

`sensitivity()` recommends the west pointing as the noise reference on the
grounds that it is line-free, and panel (a) shows it as much the flattest of
the three. But its own Gaussian fit returns an amplitude of 5.4 percent of
continuum with a 152 kHz FWHM, the broadest in the set. West has the
weakest line, not no line.

The noise recommendation survives this, because it uses the residual about a
fitted polynomial baseline over a window offset from the line, not the raw
rms. But "line-free" is the wrong word for it in a manuscript, and a 5.4
percent fitted amplitude should not be reported as a detection either.

## 7. What is now blocked

* No pointing direction for the sweep can be recovered from the files. If no
  external record of the manual sweep exists, the 12 blocks are usable only
  as repeat observations of unknown direction.
* ~~The prototype tap count needs a GNU Radio installation.~~ **Settled**
  (section 5): `firdes` returns 32 299 taps, the branches consume the first
  16 384, and the truncation is confirmed by three statistics of the real
  captures.
* The row cadence rests on inference from noise statistics. Only an external
  record of the session, or a repeat measurement with a known setting, can
  make it certain.
* Antenna temperature would have to be measured, for example against a
  known load or by a sky dip, before any kelvin quantity is quoted as
  measured.

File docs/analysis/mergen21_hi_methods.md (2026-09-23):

# Mergen-21 first-light H I figure: methods, provenance and audit

This document accompanies `mergen21_hi_analysis.py`, which regenerates the
three-panel figure and every number quoted from it, starting from the raw
GNU Radio captures in the `mergen-21` repository.

Reproduction check: the script's `mergen21_hi_line_parameters.csv` matches the
previously archived summary table digit for digit in peak amplitude, centroid,
FWHM and LSR velocity. Galactic coordinates and the motion correction differ in
the first decimal because IERS auto-download is disabled here for offline
reproducibility, an effect well below the pointing uncertainty.

The single most important provenance finding is recorded first, because it is
the reason this package exists: **the lineage attached to the published figure
artifact is the superseded analysis**, the earlier interpretation in which the
spectral feature was taken to lie *below* the rest frequency. The figure as
published therefore had no recoverable generating script. It does now.

---

## 1. Instrument configuration, as read from the flowgraph

Read from `software/gnuradio/reciver.grc`, not assumed:

| quantity | value | source |
|---|---|---|
| FFT size | 2048 | `fft_size` |
| sample rate | 2.048 MS/s | `samp_rate` |
| channel bandwidth | 1.000 kHz | `samp_rate / fft_size` |
| integrations per saved row | 500 | `integration_time` |
| integration time per row | 0.500 s | `500 x 2048 / 2.048e6` |

Saved rows are `float32` power spectra. They are **already DC-centred**: the
FFT block runs with `shift: True`, so the channel order matches
`fftshift(fftfreq(2048, 1/2.048e6))` directly. Applying a second shift, as an
earlier pass did, moves the band-centre instrumental artifact to the band edge
and places the line at a spurious offset. This is the defect that produced the
superseded "feature below the rest frequency" reading.

On-source time is 51.5 to 53.0 s for the three static pointings (103 to 106
rows) and about 12.2 s for each of the 12 sweep blocks.

## 2. Spectral windows

| window | channels | purpose |
|---|---|---|
| line | 55 to 340 kHz | line search and Gaussian fit |
| baseline | 45 to 900 kHz, both signs, line excluded | cubic continuum fit |
| reference | 250 to 750 kHz | panel (a) normalization |
| noise | 450 to 880 kHz, both signs, 406 kHz spur excised | sensitivity |

The band-centre region `|f| < 45 kHz` is excluded everywhere. It carries an
instrumental artifact reaching 4.6x the continuum, sitting exactly on the rest
frequency because the local oscillator was tuned there. Offsetting the LO by a
few hundred kHz and translating in software would avoid the overlap in future
observations.

A narrowband spur at **+406 kHz** reaches 12% of continuum in the east
pointing. It is excised from the noise window; leaving it in inflates the east
channel rms from 0.86 to 1.42 K and is the largest single window sensitivity in
the analysis.

---

## 3. The five audit questions

### 3.1 Why the south peak is 25% in panel (a) but 18% in panel (c)

Both are correct. They are different quantities, and the earlier figure did not
say which was which.

- **Panel (a), 25.1%.** The spectrum is divided by the median of the line-free
  reference band (250 to 750 kHz) and plotted. The highest single channel in
  the line window sits 25.1% above that level.
- **Panel (c), 18.13 +/- 0.28%.** A Gaussian plus a *local* linear baseline is
  fitted jointly over the line window. The plotted quantity is the Gaussian
  amplitude, i.e. the line above the continuum immediately under it.

The 7-point gap has two independent causes, both physical rather than clerical:

1. **The local baseline is not the distant reference level.** Toward the plane
   the south spectrum has a broad pedestal, visible in panel (a) as wings
   extending well past the fit window. The local linear term absorbs part of
   that pedestal, so the Gaussian amplitude measures the line above its own
   wings, while the panel (a) reading measures everything above the far-field
   continuum.
2. **A single-channel maximum is biased high.** The peak channel is the maximum
   of about 285 noisy channels, so it sits roughly 1 sigma above the true
   profile peak, whereas the fitted amplitude averages over the 77 kHz line.

Both are now tabulated per measurement, as `raw_peak_excess_pct` and
`amp_pct`, so no reader has to guess which a figure is showing. For the
manuscript, quote the fitted amplitude with its uncertainty: it is the
estimator with a defined error bar and it is what panel (c) regresses.

### 3.2 How the significance was calculated, and what it covers

The statistic is the t-ratio of a regression slope, not a peak-to-noise ratio.

Ordinary least squares of the 15 observed line centroids on the
ephemeris-predicted radial motion of the observer (barycentric correction from
`astropy` plus the projection of the solar peculiar motion onto each
sightline):

```
centroid [kHz] = 60.2 (+/- 10.0) + 2.635 (+/- 0.318) x v_motion [km/s]
r = 0.917,  residual rms 14.1 kHz,  n = 15
```

A signal at a **fixed terrestrial frequency** predicts slope 0. The measured
slope is 2.635/0.318 = **8.3 sigma** from that null. That is the origin of the
"eight sigma" claim. The identical test in velocity space, where the
terrestrial null is slope +1, gives 0.444 +/- 0.067 against 1, again 8.3 sigma.

**What the 8.3 sigma includes.** Only the OLS slope standard error, which is
built from the scatter of the 15 points about the line. That scatter contains
the spectral noise propagated through the centroid fits, plus any
short-timescale pointing jitter that moves points randomly.

**What it excludes, in order of importance.**

1. **Serial correlation between sweep blocks.** The residuals have lag-1
   autocorrelation +0.65 in time order. The naive effective sample size
   `n (1-r)/(1+r)` is 3.2 rather than 15, which rescales the slope error and
   gives **3.8 sigma**. This is the number to quote if the 15 points are
   described as independent measurements.
2. **Pointing systematics.** The mount has no positioner or encoder. Elevation
   is assumed 35 degrees from the Stellarium charts, and the sweep azimuth is
   assumed to ramp linearly from 90 to 270 degrees. These errors move the
   predicted abscissae *coherently*, so they bias the slope rather than inflate
   its error, and no part of the quoted sigma protects against them.
3. **Analysis choices.** Baseline order, fit window and centroid estimator.
   Repeating the regression with the smoothed-moment centroid used in the
   published figure gives slope 1.99 +/- 0.30, 6.6 sigma against the
   terrestrial null and 3.0 sigma after the correlation correction.

**A second number a reviewer will compute.** The fitted slope 2.635 +/- 0.318
is also 6.6 sigma *below* the 4.738 kHz per km/s expected for a single line at
rest in the LSR. That is not a failure: over the sweep the sightline crosses a
wide range of Galactic longitude and latitude, so the emission-weighted LSR
velocity is not constant and Galactic rotation flattens the relation. Stating
this pre-empts the objection.

Recommended phrasing: report the slope with its error, state that it excludes a
terrestrially fixed signal at 3.8 sigma once block correlation is accounted
for, and name the pointing assumption as the dominant systematic.

### 3.3 Whether the blue line is a prediction or a fit

**A prediction, with zero free parameters.** It is
`centroid = (f0/c) x v_motion`, slope 4.738 kHz per km/s and intercept 0, the
locus for gas at rest in the LSR. Nothing in it is fitted to these data.

The fitted regression is the separate thin dark line, and the two are now
labelled with their slopes in the legend so they cannot be conflated. In the
published version only one line was drawn and its status was ambiguous, which
is what prompted this question.

### 3.4 How sweep-block independence was assessed

In the published version it was **not assessed**. The blocks are not
independent, and the package now quantifies it two ways.

By construction, the 12 blocks are contiguous equal-row slices of a single
continuous 146 s capture, so the mount drifts through them without
interruption. Two concrete measures:

- **Beam overlap.** The assumed 180 degree sweep over 12 blocks is 15 degrees
  of azimuth per block, against simulated 3 dB beamwidths of 25.2 degrees
  (H-plane) and 22.0 degrees (E-plane). Adjacent blocks therefore share well
  over half a beamwidth of sky and cannot be independent samples.
- **Residual autocorrelation.** Lag-1 autocorrelation of the regression
  residuals in time order is +0.65, giving an effective sample size of 3.2 and
  the 3.8 sigma of section 3.2.

The honest description is 15 correlated measurements along one continuous
track, equivalent to roughly three independent pointings. The three static
pointings are genuinely separate acquisitions and are the independent core of
the argument.

### 3.5 How the 1.08 K sensitivity and the 0.6 dB cable correction were obtained

**The 1.08 K does not reproduce, and should be replaced.**

It traces to an earlier session that reported per-channel sensitivities of
1.08 K south, 1.18 K east and 0.78 K west. Recomputed here from the same
captures with a two-sided line-free window and the 406 kHz spur excised:

| pointing | baseline rms | channel-differenced | radiometer prediction | on-source |
|---|---|---|---|---|
| west  | 0.802 K | 0.648 K | 0.841 K | 53.0 s |
| south | 1.425 K | 0.634 K | 0.853 K | 51.5 s |
| east  | 0.861 K | 0.627 K | 0.849 K | 52.0 s |

Only the west value reproduces. The south value is not noise: that estimator is
dominated by the line's own wings, which is why it is insensitive to the window
choice (1.36 to 1.52 K across five reasonable windows) while the east value
moves by a factor 1.6 depending on whether the spur is excised.

Two estimators are reported because they bracket the truth:

- **Baseline rms** is the scatter of the continuum-removed spectrum over
  line-free channels. It includes residual baseline structure, so it is an
  **upper bound**, and it is meaningless where the line has wings.
- **Channel-differenced** is the robust scale of the successive-channel
  difference divided by sqrt(2), immune to baseline curvature. It reads 0.63 to
  0.65 K identically in all three pointings, as it must if T_sys and tau are
  common. An earlier version of this note called it a lower bound, on the
  reasoning that the WOLA filterbank correlates adjacent channels. That has
  since been measured on the line-free window and the lag-1 correlation is
  only +0.043 to +0.050, so the estimator is biased low by about one percent
  and is effectively **unbiased**. The earlier claim was wrong. See
  `PROVENANCE.md` section 3 for the consequence, which is that the gap
  between this estimator and the line-free scatter is residual baseline
  structure rather than channel correlation.

The radiometer equation at T_sys = 193.5 K, B = 1 kHz and tau = 52 s predicts
0.84 K, which sits inside the bracket and agrees with the line-free west
pointing to 5%.

Recommendation: quote **0.80 K, measured in the line-free west pointing**, and
note agreement with the radiometer prediction. Quoting a south-pointing rms as
a sensitivity conflates signal with noise.

**The 0.6 dB is measured, not assumed.** It is the insertion loss at 1.42 GHz
of the cable between the receiver output and the spectrum analyzer, from the
FSVA3044 trace `measurements/rf-chain/nf/cable_loss.DAT`, carried with a stated
+/- 0.2 dB tolerance in `measurements/rf-chain/nf/README.md` and cross-checked
against the reference-path loss recorded in the IP3 measurement directory.

It enters the noise figure because of a calibration-plane mismatch. The ZNB8
cascade gain was TOSM-calibrated **at the DUT ports**, which de-embeds that
cable from the gain, while the analyzer's noise-density reading still contains
its loss. The output density is therefore 0.6 dB low relative to the gain
reference plane and must be corrected upward:

```
NF = (P_out + L_cable) - kT0 - G
   = (-133.46 + 0.60) - (-173.9) - 39.5 = 1.54 dB   ->  T_rx = 123 K
uncorrected:  0.94 dB  ->  T_rx = 70 K
tolerance:    1.34 to 1.74 dB from the +/- 0.2 dB cable figure
```

The corrected 1.54 dB fails the manuscript's 0.96 dB design budget and raises
the integration needed for 1 K in a 1 kHz channel from 20 to 37 s. Because the
S-parameter sweep was wideband and coarse and cannot be repeated, T_rx is
reported as an upper bound with the calibration plane named as the dominant
systematic.

**Uncertainty on this number is incomplete, by decision rather than by
oversight.** The 1.54 dB is carried as the central estimate without a full
error budget: the cable tolerance alone spans 1.34 to 1.74 dB, and the gain
term carries a further uncertainty the coarse sweep does not resolve and that
cannot now be quantified. The manuscript states this explicitly and directs
anyone reproducing the build to measure interconnect and gain at a common
reference plane rather than adopt the value.

---

## 3.6 Decisions taken on the manuscript

Settled with the author after this audit, and now written into `main.tex`:

- The estimator clarification of section 3.1 is accepted; panels (a) and (c)
  are described as the different quantities they are, in the caption.
- The corrected 1.54 dB noise figure is retained as the central estimate,
  carrying the incomplete-uncertainty caveat above.
- **The 1.08 K is not reinstated.** Table III and the abstract now quote
  0.80 K from the line-free west pointing, with the radiometer agreement
  stated.
- **No "8 sigma confirmation" is reinstated.** The abstract, the results
  section and the figure caption quote 3.8 sigma, name the block correlation
  that forces it, and state that the elevation assumption biases the slope
  rather than widening its error.
- The peak signal-to-noise is restated as roughly 25, the fitted amplitude
  against the line-free per-channel noise, replacing the previous 33 which
  paired the raw peak with a line-contaminated noise estimate.

---

## 4. Quantities that are assumed rather than measured

These are marked `ASSUMED` inline in the script and are the honest limits of
the pointing-dependent results.

| quantity | value | why it is assumed | effect |
|---|---|---|---|
| elevation | 35 deg | no positioner or encoder on the mount; read off the Stellarium charts | dominant systematic on `l`, `b` and the motion correction |
| sweep azimuth | linear 90 to 270 deg | direction and extent from the observation log and filename; no per-row record | biases the panel (b) slope coherently |
| site | 41.0 N, 29.0 E, 100 m | no GPS fix logged | below 0.01 km/s on the motion correction |
| local time offset | UTC+3 | filenames carry local time | 1 h error would shift the motion correction by about 1 km/s |
| T_sys | 193.5 K | 70 K antenna plus 123 K receiver, the latter itself an upper bound | scales all kelvin sensitivities linearly |

## 5. Files

| file | contents |
|---|---|
| `mergen21_hi_analysis.py` | the complete analysis, one entry point |
| `mergen21_hi_measurements.csv` | 15 measurements, 31 columns |
| `mergen21_hi_line_parameters.csv` | 3-pointing summary, matches the archived table |
| `mergen21_data_manifest.csv` | sha256, byte count and row count for every input |
| `mergen21_hi_derived.json` | regressions, sensitivity, noise figure, assumptions |
| `mergen21_hi_validation.png` | the three-panel figure |

Inputs are referenced by checksum, not copied. Point the script at a checkout:

```
python mergen21_hi_analysis.py --root /path/to/mergen-21 --outdir out
```

### Columns of `mergen21_hi_measurements.csv`

`id`, `kind`, `source_file`, `utc_mid`, `n_rows`, `on_source_s`, `az_deg`,
`alt_deg`, `ra_deg`, `dec_deg`, `l_deg`, `b_deg`, `centroid_kHz`,
`centroid_err_kHz`, `centroid_moment_kHz`, `amp_pct`, `amp_err_pct`,
`smoothed_peak_pct`, `raw_peak_excess_pct`, `fwhm_kHz`, `fwhm_err_kHz`,
`fwhm_kms`, `halfpower_width_kHz`, `v_bary_kms`, `v_solar_kms`,
`v_motion_kms`, `v_lsr_kms`, `v_lsr_moment_kms`, `rms_frac`,
`dT_baseline_K`, `dT_diff_K`, `dT_radiometer_K`, `snr_peak`, `az_step_deg`.

Uncertainties on `centroid`, `amp` and `fwhm` are formal 1-sigma values from
the covariance matrix of the Gaussian-plus-linear fit. They do not include
pointing error, which is not random.

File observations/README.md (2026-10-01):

# Observations

First-light hydrogen line (1420.405 MHz) observations from Mergen-21, collected 2026-04-29 from Istanbul, Turkey (~41.0°N, 29.0°E).

## Contents

- `data/` — Raw spectra (`.dat`, NumPy float32) saved by `receiver.grc`
- `plots/` — Waterfall and directional sweep plots (PNG)
- `stellarium_*.png` — Sky reference charts for each pointing direction

## First-Light Session — 2026-04-29

Directional sweeps across the galactic plane.

| File label | Direction |
|---|---|
| `_bati` | West (Batı) |
| `_guney` | South (Güney) |
| `_doggu` / `_Dogu` | East (Doğu) |

## Stellarium Reference Charts

These are sky screenshots taken during the observation session to document where the telescope was pointing.

| File | What it shows |
|---|---|
| `stellarium_east.png` | Eastern sky at observation time |
| `stellarium_south.png` | Southern sky |
| `stellarium_west.png` | Western sky |
| `stellarium_high_fov_sweep.png` | Wide FOV showing the full sweep arc |

## Plots

Observation plots are in `plots/`:
- `east.png`, `south.png`, `west.png` — Spectra per direction
- `east_100_integration.png` — East direction with 100-sample integration
- `sweeping from east to west.png` — Full sweep waterfall

## Acquisition Settings

Per-file acquisition provenance for the 2026-04-29 session is recorded in [`captures.csv`](captures.csv), derived from the observer's confirmed capture metadata. Summary:

- The west (`_bati`), south (`_guney`), and 05:02:04 east (`_doggu`) pointings, and the sweep (`_180partygirl_500int.dat`), all ran with `integration_time = 1000` on the flowgraph (1.0 s per row).
- Only `..._050450_Dogu_100.dat` used `integration_time = 100` (0.1 s per row); this is the one file whose name correctly states its integration setting.
- The sweep file's name says "500int", but it actually ran with `integration_time = 1000`; the filename is wrong.
- Azimuths were read from two phone compasses at the time of each static pointing. Elevation (30°) was estimated by the observer and was not instrumented. The horn rested on its narrow (80 mm) wall with the N-connector axis horizontal (E-plane horizontal), not hand-held. The sweep capture has no angle log at all; it moved through pointings manually with pauses and is qualitative only (its azimuth is not recoverable and its effective bandwidth cannot be estimated by row differencing).

### Assumed quantities

These values are assumed rather than measured; they are marked `ASSUMED` in `software/analysis/mergen21_hi_analysis.py`.

| quantity | value | why it is assumed | effect |
|---|---|---|---|
| elevation | 30° | observer-stated; no positioner or encoder on the mount | dominant systematic on `l`, `b` and the motion correction |
| site | 41.0 N, 29.0 E, 100 m | no GPS fix logged | below 0.01 km/s on the motion correction |
| local time offset | UTC+3 | filenames carry local time | 1 h error would shift the motion correction by about 1 km/s |
| row cadence | 1.0 s per row (0.1 s for `..._050450_Dogu_100.dat`) | `integration_time` supplied by the observer; not stored in the `.dat` files | sets the time axis and the averaging-noise scaling |

In addition to the five captures in `captures.csv`, `data/` contains 21 earlier `.dat` files with no direction suffix (plain `mergen21_spec_20260429_HHMMSS.dat`). These are earlier test and commissioning captures; their acquisition settings were not recorded and they are not included in `captures.csv`.

## Loading the Data

These `.dat` files are the sample SDR recordings distributed with the repository.
A real antenna or SDR is not needed to view them.

```python
import numpy as np

FFT_SIZE = 2048
raw = np.fromfile('data/mergen21_spec_20260429_041703.dat', dtype=np.float32)
spectra = raw[:len(raw) // FFT_SIZE * FFT_SIZE].reshape(-1, FFT_SIZE)
avg_spectrum = spectra.mean(axis=0)   # time-averaged spectrum
```

**Interactive viewer** (run from the repository root):
```bash
python software/analysis/mergen21_waterfall_viewer.py
```

In the viewer: click **Add...**, navigate to `observations/data/`, select one or more `.dat` files, then click **Plot**. Switch the X axis to **Velocity [km/s]** to see the Doppler scale. The narrow spike at 0 km/s (exactly at the LO) is the band-center instrumental artifact, not hydrogen; the H I line is the broad hump 80 to 190 kHz above the LO (about −16 to −36 km/s on the viewer's uncorrected topocentric axis).

See [`docs/lab-manual-04-observe.md`](../docs/lab-manual-04-observe.md) for a step-by-step walkthrough.

## Site

**Location:** Istanbul, Turkey (~41.0°N, 29.0°E)  
**Target:** Galactic plane HI emission (1420.405 MHz)  
**Method (future work):** Tangent-point method for rotation curve extraction; not yet performed on the released data. What this release supports is first-light, pointing-dependent line detections (south/east/west) -- see `docs/analysis/PROVENANCE_ADDENDUM.md`.

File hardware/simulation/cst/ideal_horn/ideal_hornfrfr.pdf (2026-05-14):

Components

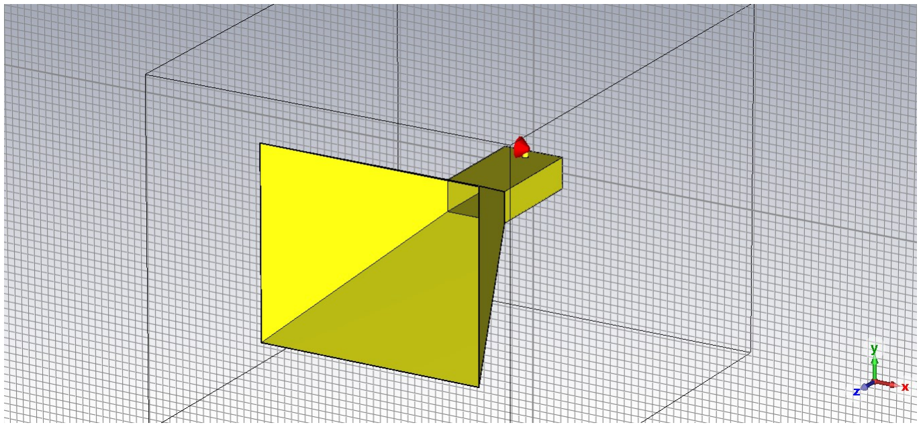
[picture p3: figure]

1D Results\S-Parameters

Farfields\farfield (f=1.42) [1]

Farfields\farfield (f=1.42) [1]

Farfields\farfield (f=1.42) [1]

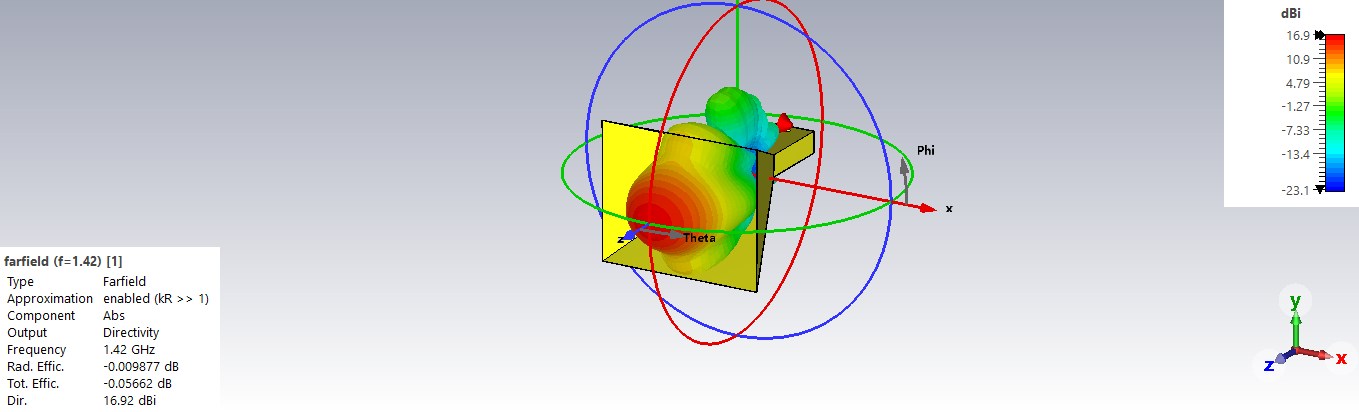
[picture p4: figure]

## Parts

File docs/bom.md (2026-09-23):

# Bill of Materials

Complete component list for the Mergen-21 21 cm radio telescope.

> **Part number notes:** Mini-Circuits parts can be ordered directly from
> [minicircuits.com](https://www.minicircuits.com) using the model number as the
> ordering code, or through Mouser Electronics (manufacturer prefix **723-**).
> Distributor part numbers marked † should be verified at checkout; they are
> correct as of mid-2026 but stock codes occasionally change.

> **Currency:** USD prices are the reference (Mini-Circuits, Digi-Key, and
> Mouser price in USD). TRY figures are converted at **1 USD ≈ 47.35 TRY**
> (27 July 2026, exchange-rates.org / tradingeconomics.com) and will drift with
> the exchange rate; use the USD column for ordering, TRY for budgeting.

---

## RF Front-End

| Qty | Description | Manufacturer | Mfr Part No. | Mouser P/N | Approx. Price (USD) | Approx. Price (TRY) |
|-----|---|---|---|---|---|---|
| 1 | Low-noise amplifier, 50–1600 MHz, NF 0.7 dB, G 19.7 dB | Mini-Circuits | ZX60-P162LN+ | 723-ZX60-P162LN+ † | $49.95 | ₺2,365 |
| 1 | Bandpass filter, 1450 MHz center, ~50 MHz BW | Mini-Circuits | ZX75BP-1450-S+ | 723-ZX75BP-1450-S+ † | $89.95 | ₺4,259 |
| 1 | Amplifier, 50–6000 MHz, G 20.8 dB | Mini-Circuits | ZX60-V63+ | 723-ZX60-V63+ † | $39.95 | ₺1,892 |

**Sub-total RF chain: ~$180 / ~₺8,523**

---

## SDR Backend

| Qty | Description | Manufacturer | Mfr Part No. | Digi-Key P/N | Approx. Price (USD) | Approx. Price (TRY) |
|-----|---|---|---|---|---|---|
| 1 | Software-defined radio, 70 MHz–6 GHz, 12-bit ADC | Analog Devices | ADALM-PLUTO | ADALM-PLUTO-ND † | $149–$249 | ₺7,055–₺11,790 |

---

## LDO Power Supply PCB

The PCB gerbers are in `hardware/ldo-regulator/gerbers/`. Fabricate at any PCB house (JLC, OSH Park, etc.): 2-layer, no special stack-up required.

| Qty | Description | Manufacturer | Mfr Part No. | Digi-Key P/N | Approx. Price (USD) | Approx. Price (TRY) |
|-----|---|---|---|---|---|---|
| 2 | Ultra-low-noise LDO regulator, 1 A, adjustable | Texas Instruments | TPS7A4701RGWT | 296-TPS7A4701RGWT-ND † | $3.50 each | ₺166 each |
| — | Resistors, capacitors (per schematic `hardware/ldo-regulator/schematic.pdf`) | Various | See BOM PDF | — | ~$5 total | ~₺237 total |
| 1 | PCB fabrication (double-sided, 2-layer) | — | — | — | ~$15–30 | ~₺710–₺1,420 |

**Sub-total LDO board: ~$30 / ~₺1,420**

---

## Antenna Structure

| Qty | Description | Specification | Supplier | Approx. Price (USD) | Approx. Price (TRY) |
|-----|---|---|---|---|---|
| 1 set | Aluminum sheet for horn panels | Alloy 5754-H22, 1.5 mm thick, ~400 × 400 mm | Local metal supplier or online | ~$20 | ~₺947 |
| 1 | N-type female chassis connector (waveguide feed) | Amphenol RF 000-49000-SRFX | [Digi-Key](https://www.digikey.com/en/products/detail/amphenol-rf/000-49000-SRFX/4746416) | ~$8 | ~₺379 |
| 1 | Copper wire 1.0 mm diameter, ~50 mm | Pure copper | Electronics supplier | ~$1 | ~₺47 |
| 1 pkg | M3 × 30 mm stainless steel bolts (DIN 965TX), M3 × 8 mm (DIN 7985TX), M3 nuts (DIN 934), M3 flat + spring washers | A2-304 stainless steel | Hardware store | ~$8 | ~₺379 |

**Sub-total antenna: ~$37 / ~₺1,752**

---

## Cables and Adapters

| Qty | Description | Approx. Price (USD) | Approx. Price (TRY) |
|-----|---|---|---|
| 1 | SMA male – N-type male coaxial cable, ~0.3 m, 50 Ω | ~$12 | ~₺568 |
| 1–2 | SMA male–male adapter (as needed) | ~$5 | ~₺237 |

**Sub-total cables: ~$17 / ~₺805**

---

## Optional / Not Required for Basic Operation

| Qty | Description | Notes |
|-----|---|---|
| 1 set | 3D-printed tripod mount | STL files in `hardware/antenna/stl/`; mount was prototyped but not used in final observations |

---

## Total System Cost

| Subsystem | Approx. Cost (USD) | Approx. Cost (TRY) |
|---|---|---|
| RF front-end | $180 | ₺8,523 |
| SDR (ADALM-PLUTO) | $149–$249 | ₺7,055–₺11,790 |
| LDO power supply board | $30 | ₺1,420 |
| Antenna structure | $37 | ₺1,752 |
| Cables and adapters | $17 | ₺805 |
| **Total** | **~$413–$513** | **~₺19,556–₺24,291** |

> The lower bound (~$413 / ~₺19,556) applies when the PlutoSDR is purchased at
> the student price or on sale. The main cost driver is the ADALM-PLUTO SDR and
> the ZX75BP-1450-S+ bandpass filter. Both can be substituted with cheaper
> alternatives at the cost of increased out-of-band interference. TRY figures
> use 1 USD ≈ 47.35 TRY (27 July 2026) and should be re-checked at time of
> purchase.

---

## Not Included (lab equipment)

The following items are assumed to be available in a university laboratory and are not included in the cost above:

- Vector network analyzer (for antenna and RF chain characterization): e.g. R&S ZNB8
- Spectrum analyzer with noise figure option (for NF and IP3 measurements)
- DC bench power supply (for LDO board)
- Soldering station

These instruments are only needed for the characterization labs (Lab 3). Labs 1, 2, and 4 do not require them.

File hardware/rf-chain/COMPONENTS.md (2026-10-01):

# Component Cross-Reference Index

Quick-reference mapping each RF chain component to its manufacturer data, lab measurements, and simulation files.

## RF Chain Signal Path

```
Antenna → ZX60-P162LN+ (LNA) → ZX75BP-1450-S+ (BPF) → ZX60-V63+ (Amp) → SDR
           Stage 1                 Stage 2                 Stage 3
```

## Component Index

### Stage 1: ZX60-P162LN+ (Low-Noise Amplifier)

| Resource | Path |
|---|---|
| Manufacturer PDF | [`datasheets/ZX60-P162LN+.pdf`](datasheets/ZX60-P162LN+.pdf) |
| Manufacturer S2P (-45 C) | [`datasheet-s-parameters/ZX60-P162LN+/ZX60-P162LN+_4V_Minus45degC.s2p`](datasheet-s-parameters/ZX60-P162LN+/ZX60-P162LN+_4V_Minus45degC.s2p) |
| Manufacturer S2P (+25 C) | [`datasheet-s-parameters/ZX60-P162LN+/ZX60-P162LN+_4V_Plus25degC.s2p`](datasheet-s-parameters/ZX60-P162LN+/ZX60-P162LN+_4V_Plus25degC.s2p) |
| Manufacturer S2P (+85 C) | [`datasheet-s-parameters/ZX60-P162LN+/ZX60-P162LN+_4V_Plus85degC.s2p`](datasheet-s-parameters/ZX60-P162LN+/ZX60-P162LN+_4V_Plus85degC.s2p) |
| VNA measurement | [`../../measurements/rf-chain/vna/ZX60-P162LN+/measured_ZX60-P162LN+.s2p`](../../measurements/rf-chain/vna/ZX60-P162LN+/measured_ZX60-P162LN+.s2p) |
| VNA plot | [`../../measurements/rf-chain/vna/ZX60-P162LN+/measured_ZX60-P162LN+.pdf`](../../measurements/rf-chain/vna/ZX60-P162LN+/measured_ZX60-P162LN+.pdf) |
| IP3 measurements | [`../../measurements/rf-chain/ip3/lna/`](../../measurements/rf-chain/ip3/lna/) |

### Stage 2: ZX75BP-1450-S+ (Bandpass Filter)

| Resource | Path |
|---|---|
| Manufacturer PDF | [`datasheets/ZX75BP-1450-S+.pdf`](datasheets/ZX75BP-1450-S+.pdf) |
| Manufacturer S2P (-40 C) | [`datasheet-s-parameters/ZX75BP-1450-S+/ZX75BP-1450-S+_Minus40degC.s2p`](datasheet-s-parameters/ZX75BP-1450-S+/ZX75BP-1450-S+_Minus40degC.s2p) |
| Manufacturer S2P (+25 C) | [`datasheet-s-parameters/ZX75BP-1450-S+/ZX75BP-1450-S+_Plus25degC.s2p`](datasheet-s-parameters/ZX75BP-1450-S+/ZX75BP-1450-S+_Plus25degC.s2p) |
| Manufacturer S2P (+85 C) | [`datasheet-s-parameters/ZX75BP-1450-S+/ZX75BP-1450-S+_Plus85degC.s2p`](datasheet-s-parameters/ZX75BP-1450-S+/ZX75BP-1450-S+_Plus85degC.s2p) |
| VNA measurement | [`../../measurements/rf-chain/vna/ZX75BP-1450-S+/measured_ZX75BP-1450-S+.s2p`](../../measurements/rf-chain/vna/ZX75BP-1450-S+/measured_ZX75BP-1450-S+.s2p) |
| VNA plot | [`../../measurements/rf-chain/vna/ZX75BP-1450-S+/measured_ZX75BP-1450+.pdf`](../../measurements/rf-chain/vna/ZX75BP-1450-S+/measured_ZX75BP-1450+.pdf) |
| IP3 measurements | N/A (passive component -- IP3 not applicable) |

### Stage 3: ZX60-V63+ (Second-Stage Amplifier)

| Resource | Path |
|---|---|
| Manufacturer PDF | [`datasheets/ZX60-V63+.pdf`](datasheets/ZX60-V63+.pdf) |
| Manufacturer S2P (-45 C) | [`datasheet-s-parameters/ZX60-V63+/ZX60-V63+_5V_Minus45DegC.s2p`](datasheet-s-parameters/ZX60-V63+/ZX60-V63+_5V_Minus45DegC.s2p) |
| Manufacturer S2P (+25 C) | [`datasheet-s-parameters/ZX60-V63+/ZX60-V63+_5V_Plus25DegC.s2p`](datasheet-s-parameters/ZX60-V63+/ZX60-V63+_5V_Plus25DegC.s2p) |
| Manufacturer S2P (+85 C) | [`datasheet-s-parameters/ZX60-V63+/ZX60-V63+_5V_Plus85DegC.s2p`](datasheet-s-parameters/ZX60-V63+/ZX60-V63+_5V_Plus85DegC.s2p) |
| VNA measurement | [`../../measurements/rf-chain/vna/ZX60-V63+/measured_ZX60-V63+.s2p`](../../measurements/rf-chain/vna/ZX60-V63+/measured_ZX60-V63+.s2p) |
| VNA plot | [`../../measurements/rf-chain/vna/ZX60-V63+/measured_ZX60-V63+.pdf`](../../measurements/rf-chain/vna/ZX60-V63+/measured_ZX60-V63+.pdf) |
| IP3 measurements | [`../../measurements/rf-chain/ip3/amplifier/`](../../measurements/rf-chain/ip3/amplifier/) |

### Full Cascade

| Resource | Path |
|---|---|
| VNA measurement (cascade) | [`../../measurements/rf-chain/vna/cascade/cascaded chain.s2p`](../../measurements/rf-chain/vna/cascade/cascaded%20chain.s2p) |
| VNA plot (cascade) | [`../../measurements/rf-chain/vna/cascade/cascade chain.pdf`](../../measurements/rf-chain/vna/cascade/cascade%20chain.pdf) |
| IP3 measurements (cascade) | [`../../measurements/rf-chain/ip3/cascade/`](../../measurements/rf-chain/ip3/cascade/) |
| AWR cascade simulation | [`../simulation/awr/rf_chain_cascaded.s2p`](../simulation/awr/rf_chain_cascaded.s2p) |

## Datasheets vs. S-Parameter Files

| Type | What it is | Format | Location |
|---|---|---|---|
| **PDF Datasheet** | Complete manufacturer data sheet with specifications, application notes, pin diagrams, absolute maximum ratings, and typical performance curves | `.pdf` | [`datasheets/`](datasheets/) |
| **S-Parameter File** | Frequency-dependent scattering parameters (S11, S21, S12, S22) extracted from the manufacturer's characterization data. Used for circuit simulation and cascade analysis. | `.s2p` (Touchstone) | [`datasheet-s-parameters/`](datasheet-s-parameters/) |
| **VNA Measurement** | S-parameters measured in-house with a calibrated VNA. Reflects the actual device performance (including connectors and bias). | `.s2p` + `.pdf` | [`../../measurements/rf-chain/vna/`](../../measurements/rf-chain/vna/) |

The manufacturer S-parameter files come from Mini-Circuits' website and are provided at multiple temperatures (-45/40 C, +25 C, +85 C). The VNA measurements were taken at room temperature on the actual modules, which are connectorized SMA units (not mounted on a PCB).

## Missing Data

<!-- Update this section as data is added -->
- [ ] Add per-stage NF comparison table once stage-level noise measurements are available.

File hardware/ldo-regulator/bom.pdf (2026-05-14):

Comment | Description | Designator | Footprint | LibRef | Quantity
10uF16VDC | CL31B106KOHNNNE1 0uF16VDC | C1, C2, C6, C7 | CAPC1206(3216)170_ M | CMP-1037-03125-1 | 4
47uF10VDC | CL31A476MPHNNN 47uF10V | C3, C4, C8, C9 | CAPC1206(3216)170_ M | CMP-1037-03125-1 | 4
1uF50VDC | CC1206KKX7R7BB105 1uF50VDC | C5, C10 | CAPC1206(3216)170_ M | CMP-1037-03125-1 | 2
150120BS75000 | WL-SMCWSMTMono-Color Chip LED Waterclear | D1 | WL-SMCW_1206_150120x x75000 | CMP-1426-00015-3 | 1
200mA/500mA1206 PTC | PTCRESETFUSE6V4A 1206 | F1 | FP-nanoSMD400LR-IPC_A | CMP-08606-000072-1 | 1
1843606 | 1843606Phoenix Contact 1843606MCV 1, 5/ 2-G-3, 52Way Terminal Block Header 8A3.5mm | J1, J2, J3 | FP-1843606-MFG | CMP-00298-00064326-1 | 3
M22-2510205 | CONNHEADERVERT 2POS2MM | J4 | FP-M22-2510205-MFGCMP-15831-000005-1 | | 1
8.2kOhm | 8.2kOhm1206 | R1 | FP-RMCF1206-IPC_A | CMP-26527-000539-1 | 1
TPS7A4701RGWT | ICREGLINEARPOS ADJ1A20VQFN | U1, U2 | FP-RGW0020A-MFG | CMP-04917-000017-1 | 2

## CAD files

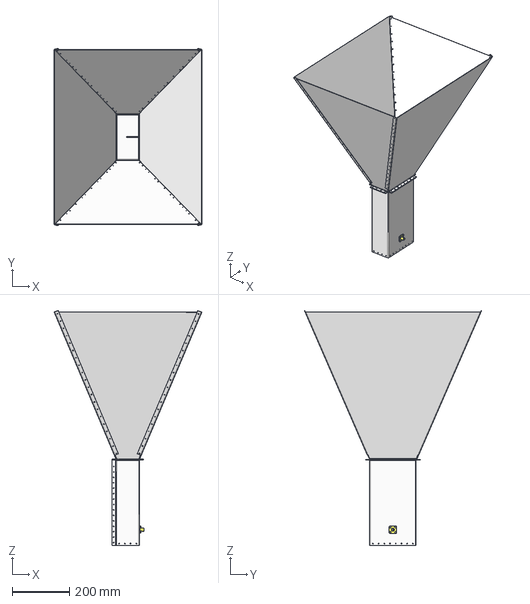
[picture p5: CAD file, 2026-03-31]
hardware/simulation/cst/assembly_worstcase/hornffrfr_assembly_worstcase.stp
516.5 x 618.4 x 820.5 mm

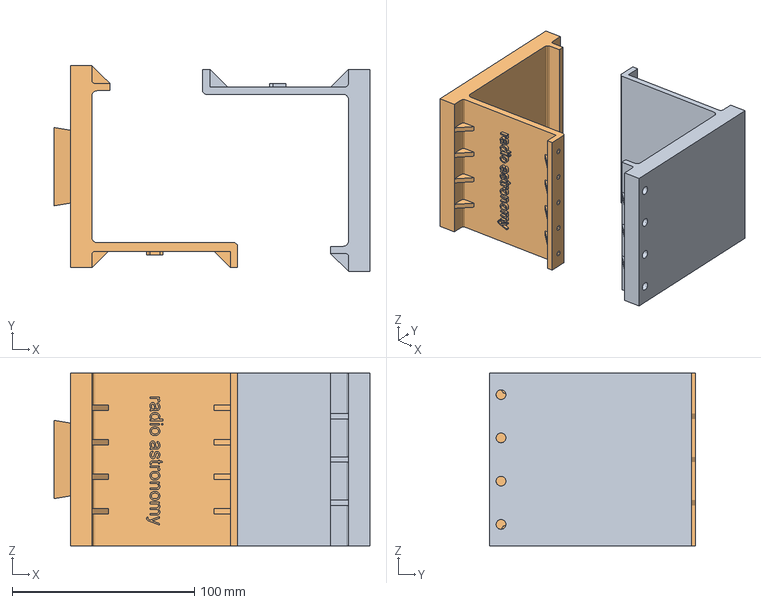
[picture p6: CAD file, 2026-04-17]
hardware/antenna/3d-print/tripode_mount.3mf
173.5 x 113.0 x 95.0 mm
tripode_mount_top.stl
tripode_mount_bottom.stl

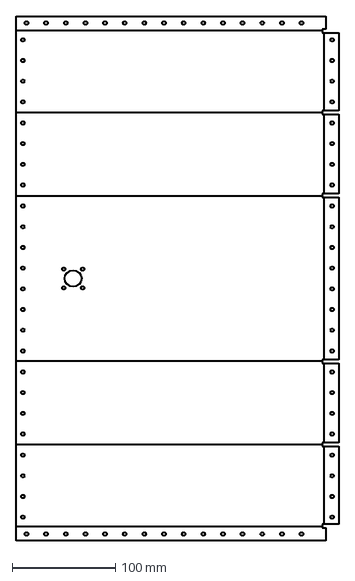
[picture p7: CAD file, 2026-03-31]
hardware/antenna/dxf/wave_0.1.dxf
312.1 x 507.2 mm

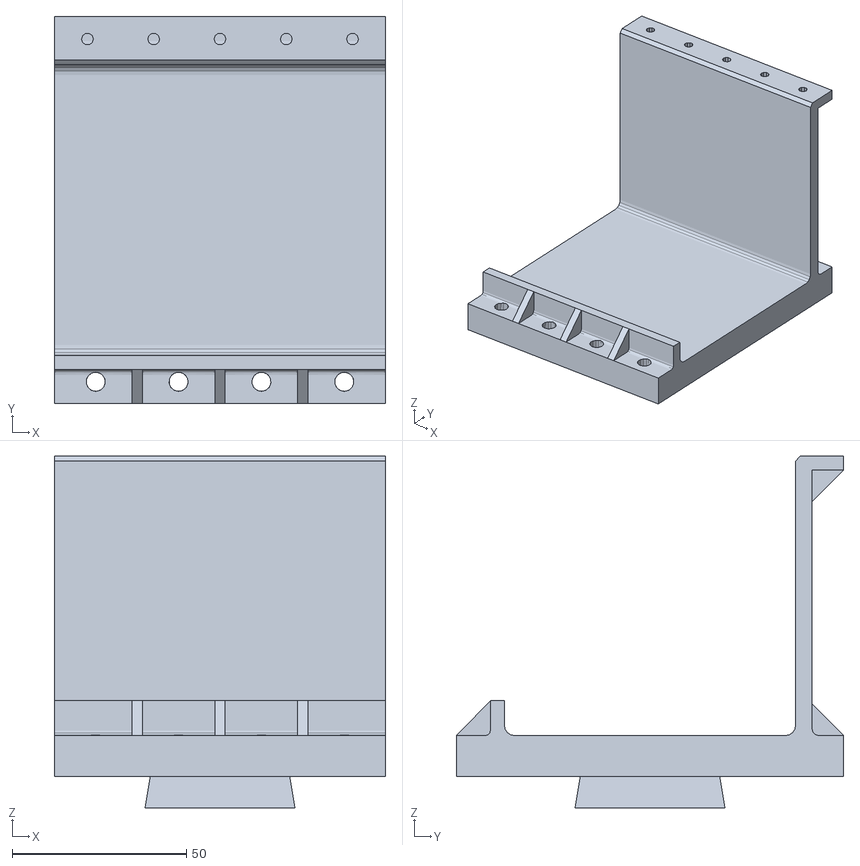
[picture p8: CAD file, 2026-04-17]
hardware/antenna/stl/tripode_mount_bottom.stl
95.0 x 111.0 x 100.9

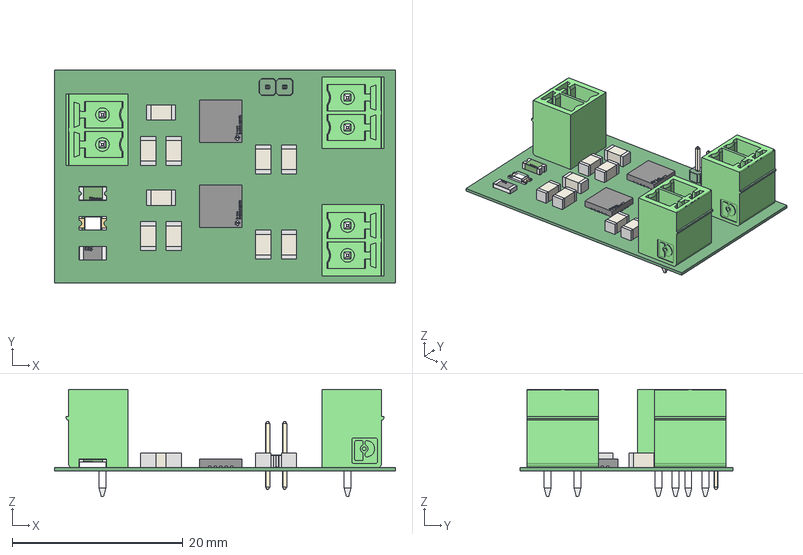
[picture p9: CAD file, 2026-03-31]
hardware/ldo-regulator/PCB1.step
40.0 x 25.0 x 12.6 mm
Leads x 2
Conn_Phoenix_Contact_1843606_eec x 9
pins x 2
logo x 4
terminals x 2
top
housing
cover
base x 2
marking
Extruded x 30

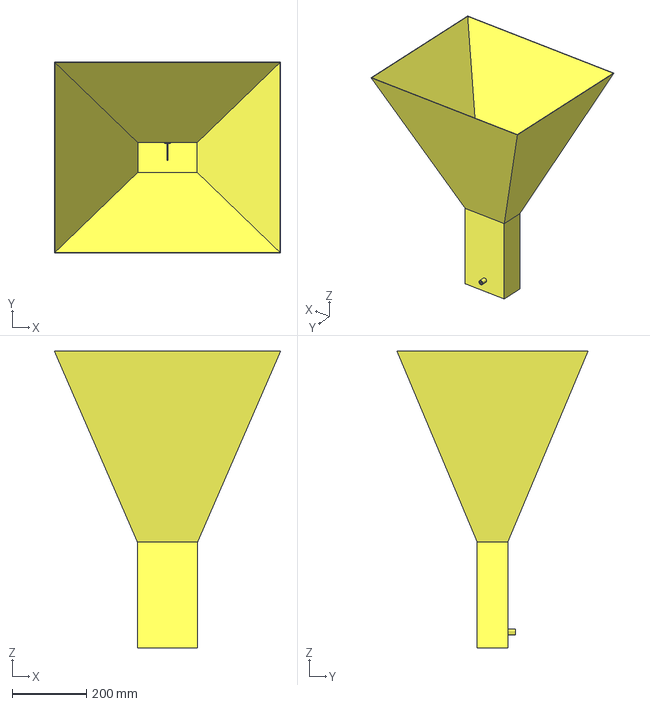
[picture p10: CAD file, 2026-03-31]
hardware/simulation/cst/ideal_horn/ideal_hornfrfr.stp
611.3 x 516.3 x 801.7 mm

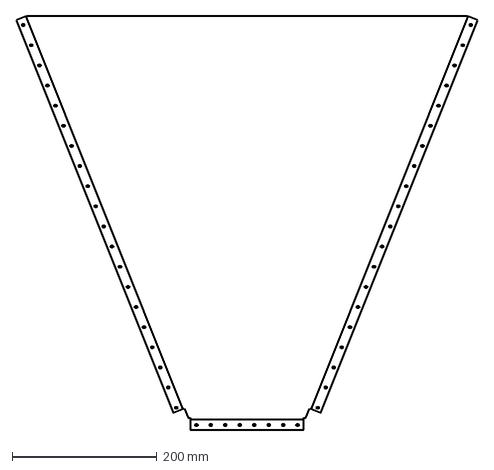
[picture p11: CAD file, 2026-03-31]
hardware/antenna/dxf/hplane_v0.3.dxf
638.3 x 572.1 mm

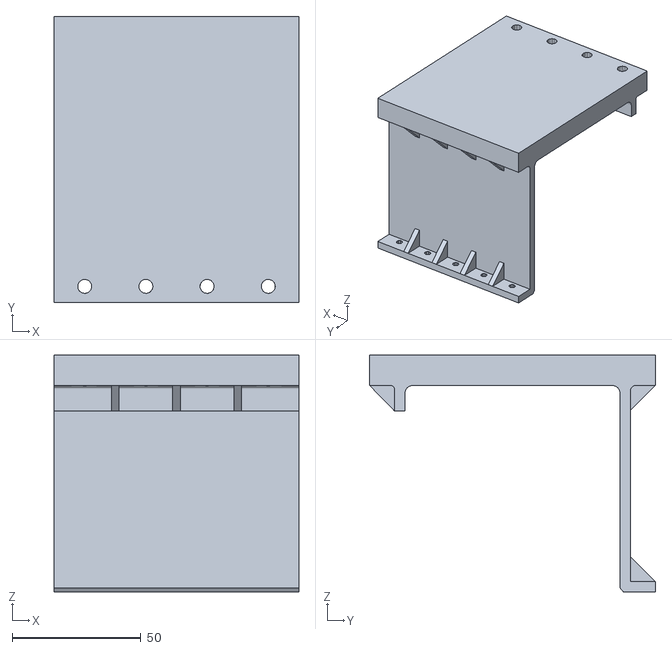
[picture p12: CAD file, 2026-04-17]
hardware/antenna/stl/tripode_mount_top.stl
95.0 x 111.0 x 91.9

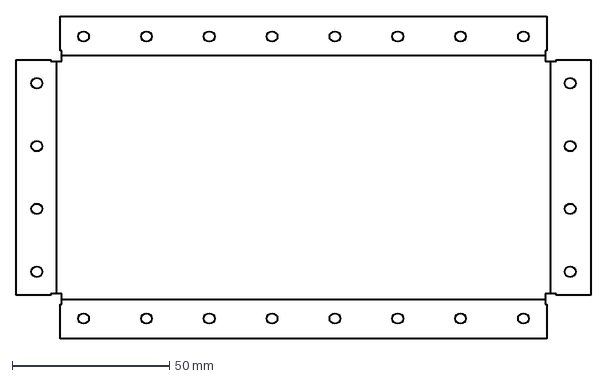
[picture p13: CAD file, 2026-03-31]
hardware/antenna/dxf/backshort_0.1.dxf
182.8 x 102.8 mm

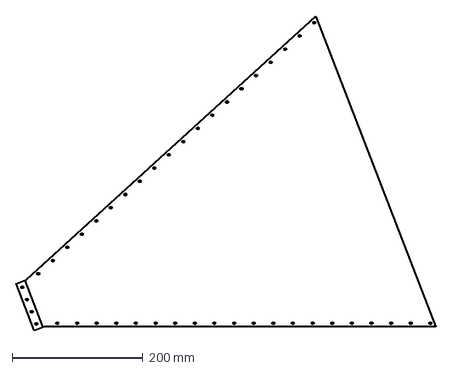
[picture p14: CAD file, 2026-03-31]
hardware/antenna/dxf/eplane_v0.3.dxf
641.1 x 480.4 mm

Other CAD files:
hardware/antenna/inventor/backshort_0.1.ipt
hardware/antenna/inventor/eplane_v0.3.ipt
hardware/antenna/inventor/horn_v0.1.iam
hardware/antenna/inventor/hplane_v0.3.ipt
hardware/antenna/inventor/tripode_mount.ipt
hardware/antenna/inventor/tripode_mount_bottom.ipt
hardware/antenna/inventor/tripode_mount_top.ipt
hardware/antenna/inventor/wave_0.1.ipt

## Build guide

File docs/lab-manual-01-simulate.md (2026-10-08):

# Lab Manual 1: Simulate

**Topic:** Electromagnetic simulation of the horn antenna and RF cascade analysis  
**Estimated time:** 3–4 hours  
**Prerequisites:** Basic knowledge of electromagnetic simulation concepts; familiarity with S-parameters

---

## Learning Objectives

After completing this lab, students will be able to:

1. Build a parametric pyramidal horn antenna model in CST Studio Suite using a provided VBA macro.
2. Interpret S11, far-field directivity, and beamwidth simulation results.
3. Understand the effect of manufacturing tolerances on antenna performance (ideal vs. worst-case).
4. Analyze a cascaded RF chain using S-parameter files and Friis noise-figure formulas.
5. Predict the system noise figure of a multi-stage receiver using AWR or Python.

---

## Part A: Horn Antenna Simulation (CST Studio Suite)

### Required Software

- CST Studio Suite 2023 or later (frequency-domain tetrahedral solver)
- Any version that supports VBA macros and frequency-domain simulation

### Files Needed (from this repository)

| File | Location |
|---|---|
| VBA macro (rebuilds full model) | `hardware/simulation/cst/ideal_horn/ideal_hornfrfr_creator.mcs.bas` |
| Design parameters | `hardware/simulation/cst/ideal_horn/ideal_hornfrfr_all_parameters.txt` |
| Expected S11 result | `hardware/simulation/cst/ideal_horn/ideal_hornfrfr.s1p` |
| Expected far-field, H-plane (cut through the 608 mm aperture side) | `hardware/simulation/cst/ideal_horn/ideal_hornfrfr_farfield_phi0.txt` |
| Expected far-field, E-plane (cut through the 514 mm aperture side) | `hardware/simulation/cst/ideal_horn/ideal_hornfrfr_farfield_phi90.txt` |

### Procedure

#### A1: Create the parametric model

1. Open CST Studio Suite. Create a new **Microwave & RF** project.
2. In the VBA Macro editor (menu: **Macros → Edit/Run VBA Macros**), open and run `ideal_hornfrfr_creator.mcs.bas`. This macro creates the complete 3D geometry, assigns materials, defines the coaxial port, and sets solver parameters. No manual geometry entry is required.
3. After the macro finishes, verify that the model contains the following components:
   - Horn body (four aluminum panels forming the pyramidal section)
   - Rectangular waveguide section (WR-650 equivalent)
   - Backshort (short-circuit termination at the rear of the waveguide)
   - N-type coaxial feed probe (copper wire)

#### A2: Review design parameters

Open `ideal_hornfrfr_all_parameters.txt` and note the key geometric values. The design is optimized for 1420.405 MHz (the neutral hydrogen 21 cm line). Important parameters include:

- Aperture dimensions (E-plane height, H-plane width)
- Flare length
- Probe depth and diameter
- Backshort distance (distance from probe to waveguide end wall)

These values can be changed in the CST parameter editor to explore sensitivity.

#### A3: Run the simulation

1. Set the frequency range to **1–2 GHz** in the solver settings.
2. Select the **Frequency-Domain (FD) tetrahedral** solver with adaptive mesh refinement.
3. Run the simulation. Expected runtime: 30–90 minutes depending on workstation.

#### A4: Analyze results

After the simulation completes, open the results navigator and extract:

| Result | How to access | Expected value |
|---|---|---|
| S11 (reflection coefficient) | Results → S-Parameters → S1,1 | ≈ −19.7 dB at 1420 MHz (minimum ≈ −30.7 dB at 1396 MHz) |
| Peak directivity | Farfield → Farfield Plots | ≈ 16.9 dBi at 1420 MHz |
| H-plane 3 dB beamwidth | Farfield, cut through the 608 mm aperture side | ≈ 25.2° |
| E-plane 3 dB beamwidth | Farfield, cut through the 514 mm aperture side | ≈ 22.0° |

Compare your S11 curve against `ideal_hornfrfr.s1p`. They should match exactly (the `.s1p` was exported from the same model).

#### A5: Manufacturing tolerance study (optional, 1 extra hour)

The `assembly_worstcase/` folder contains simulation results for a model that includes assembly imperfections: gaps at panel seams, added bridging blocks, and individually modeled screws. This represents the realistic worst case after fabrication.

1. Open `assembly_worstcase/hornffrfr_assembly_worstcase.stp` in CST as an imported geometry. Add the same materials and port as the ideal model.
2. Compare the simulated S11 against `hornffrfr_assembly_worstcase.s1p`.

**Discussion question:** What is the degradation in S11 depth and frequency shift caused by realistic assembly tolerances? Is the antenna still well-matched at 1420 MHz?

---

## Part B: RF Cascade Analysis

### Files Needed

| File | Location |
|---|---|
| S2P files for each stage | `hardware/rf-chain/datasheet-s-parameters/` |
| AWR noise figure data | `hardware/simulation/awr/ZX60_P162LN_NF.txt`, `ZX60_V63_NF.txt` |
| Simulated cascade S2P | `hardware/simulation/awr/rf_chain_cascaded.s2p` |
| Cascade gain plot | `hardware/simulation/awr/rf_chain_gain.png` |

### Background

The receiver RF chain consists of three stages in series:

```
Antenna → [ZX60-P162LN+] → [ZX75BP-1450-S+] → [ZX60-V63+] → SDR
           LNA: G=19.7 dB    BPF: IL=0.8 dB      Amp: G=20.8 dB
           NF=0.7 dB         NF=0.8 dB             NF=3.7 dB
```

### Procedure

#### B1: Manual Friis calculation

Using the Friis formula for cascaded noise figure:

$$F_{sys} = F_1 + \frac{F_2 - 1}{G_1} + \frac{F_3 - 1}{G_1 G_2}$$

where F is the noise factor (linear), G is the available gain (linear).

Given the datasheet values:

| Stage | Gain G (dB) | NF F (dB) |
|---|---|---|
| ZX60-P162LN+ (LNA) | 19.7 | 0.7 |
| ZX75BP-1450-S+ (BPF) | −0.8 | 0.8 |
| ZX60-V63+ (Amp) | 20.8 | 3.7 |

Calculate the cascaded noise figure and compare it to the measured value of **about 1.5 dB (cable-corrected)** (see `measurements/rf-chain/nf/`).

#### B2: S-parameter cascade in Python

The following Python code loads the stage S-parameter files and computes the cascade using a simple S21 chain multiplication (for gain/loss only):

```python
import numpy as np

def read_s2p(filename):
    """Read a 2-port Touchstone .s2p file, return (freq_hz, S21_complex)."""
    data = []
    with open(filename) as f:
        for line in f:
            line = line.strip()
            if not line or line.startswith('!') or line.startswith('#'):
                continue
            vals = [float(v) for v in line.split()]
            # Standard Touchstone format: freq S11_re S11_im S21_re S21_im ...
            freq = vals[0]  # Hz or GHz depending on header: check # line
            s21 = complex(vals[3], vals[4])
            data.append((freq, s21))
    freq = np.array([d[0] for d in data])
    s21  = np.array([d[1] for d in data])
    return freq, s21

# Load S-parameter files (adjust paths as needed)
f1, s21_lna = read_s2p('hardware/rf-chain/datasheet-s-parameters/ZX60-P162LN+/ZX60-P162LN+_4V_Plus25degC.s2p')
f2, s21_bpf = read_s2p('hardware/rf-chain/datasheet-s-parameters/ZX75BP-1450-S+/ZX75BP-1450-S+_Plus25degC.s2p')
f3, s21_amp = read_s2p('hardware/rf-chain/datasheet-s-parameters/ZX60-V63+/ZX60-V63+_5V_Plus25DegC.s2p')

# Interpolate to common frequency grid, compute cascade |S21|
# (See NumPy documentation for np.interp)
```

**Expected result:** The cascade gain near 1420 MHz should be approximately **+39.5 dB +/- 0.5 dB**, matching `hardware/simulation/awr/rf_chain_gain.png`. Note that the measured VNA cascade file has no sample exactly at 1420.405 MHz (~42.5 MHz point spacing).

#### B3: Comparison with measured results

The VNA measurements in `measurements/rf-chain/vna/` were taken with the actual components. Load `cascade/cascaded chain.s2p` and overlay it with the simulation output. Discuss:

1. How well do the datasheet S-parameters predict the measured cascade gain?
2. At what frequencies is the prediction least accurate? Why?

---

## Expected Results Summary

| Metric | Simulated | Measured |
|---|---|---|
| Horn S11 at 1420 MHz | −19.7 dB (ideal model), −21.8 dB (worst-case model) | −41.8 dB at the 1420.000 MHz sample; better than −30 dB from 1410 to 1440 MHz (10 MHz grid) |
| Horn directivity at 1420 MHz | 16.9 dBi | — (no measurement setup available) |
| Cascade gain near 1420 MHz | ~39.5 dB | 39.5 dB +/- 0.5 dB (no VNA sample exactly at 1420.405 MHz) |
| Cascade NF | 0.81 dB (Friis, VNA gains) | about 1.5 dB (1.54 dB, cable-corrected) |

---

## Troubleshooting

**CST macro fails to run:** Verify that the macro language is set to VBA (not Python). Go to Macros → Macro Language → VBA.

**S-parameter file won't load:** The `.s2p` files use standard Touchstone format. If importing into a non-standard tool, ensure the tool handles RI (Real-Imaginary) format, which is what Mini-Circuits exports.

**Simulated S11 resonance is off-frequency:** Check that the frequency unit in the CST project matches the values in the parameter file (millimetres vs. metres).

---

## Further Reading

- Pozar, D.M. (2011). *Microwave Engineering*, 4th ed., Chapter 4 (noise) and Chapter 13 (horn antennas).
- Mini-Circuits application note AN-60-010: Cascaded IP3 and NF calculations.
- CST Studio Suite online documentation: Frequency-Domain Solver.

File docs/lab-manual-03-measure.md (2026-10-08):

# Lab Manual 3: Measure

**Topic:** VNA characterization of the antenna and RF chain; noise figure and IP3 measurements  
**Estimated time:** 4–5 hours  
**Prerequisites:** Lab 2 complete (assembled hardware); access to a VNA and spectrum analyzer

---

## Learning Objectives

After completing this lab, students will be able to:

1. Calibrate a VNA (SOLT or equivalent) and measure antenna S11.
2. Measure two-port S-parameters (gain and input/output match) of a cascaded RF chain.
3. Measure noise figure using the Y-factor method (the Mergen-21 reference value was obtained with the gain method; see Part C).
4. Measure the third-order intercept point (OIP3) using a two-tone test.
5. Compare measured performance against simulation predictions (Lab 1) and datasheet values.

---

## Equipment Required

| Instrument | Specification | Used in |
|---|---|---|
| Vector network analyzer (VNA) | 1-port or 2-port, 1–2 GHz minimum | S11, S21 |
| Calibration kit | Matched to VNA connector type (SMA or N) | VNA calibration |
| Spectrum analyzer | NF measurement option preferred; 1–2 GHz | NF, IP3 |
| Noise source | Calibrated ENR at 1420 MHz, SMA | NF |
| Signal generator (x2 for IP3) | 1400–1440 MHz, ≥ +10 dBm output | IP3 |
| DC power supply | 4 V (LNA) and 5 V (amplifier), 1 A minimum | RF chain bias |
| Coaxial cables | SMA male-male, low-loss, 30–50 cm | All |
| Attenuators (10–30 dB) | SMA, rated > 0 dBm | IP3 |

---

## Part A: Antenna S11 Measurement

### Files Produced

Compare your measured files against the five sequential measurements in `measurements/antenna/`, which document the evolution from first assembly to final optimized antenna:

| Measurement | File |
|---|---|
| 1: Outdoor, uncalibrated | `measurements/antenna/1_outside_uncalibrated/alp_anten_uncal_0.s1p` |
| 2: Outdoor, VNA-calibrated | `measurements/antenna/2_outside_calibrated/alp_anten_cal_0.s1p` |
| 3: Indoor lab, calibrated | `measurements/antenna/3_inside_calibrated/alp_anten_lab_0.s1p` |
| 4: Indoor, aluminum foil on panels | `measurements/antenna/4_inside_aluminum_foil/alp_anten_lab_0_enhanced.s1p` |
| 5: Indoor, backshort cleaned | `measurements/antenna/5_inside_cleaned_backshort/anten_son_horn.s1p` |

### Procedure

#### A1: VNA calibration

1. Connect the calibration kit to the VNA port that will connect to the antenna.
2. Perform a full 1-port SOLT calibration at the measurement plane (the cable end where the antenna will connect).
3. Set the frequency range to **1.3–1.6 GHz** to capture the full resonance including off-target peaks.
4. Use at least **201 frequency points** (more is better for resolving the resonance shape).
5. Verify calibration: connect a SOLT short and verify |S11| = 0 dB; connect SOLT open and verify |S11| = 0 dB; connect SOLT load and verify |S11| ≤ −40 dB.

#### A2: First measurement (antenna in free space)

1. Connect the antenna N-type port to the VNA via the calibrated cable.
2. Face the antenna aperture away from walls and other metal surfaces (outdoors is ideal; otherwise aim at an RF-absorbing wall or at the ceiling of a large room).
3. Record S11 as a Touchstone .s1p file.
4. Note the frequency of minimum S11 (the resonance) and its depth.

**Expected result:** S11 < −20 dB at or near 1420.405 MHz.

If S11 is only −10 to −15 dB, check:
- Cable and connector quality (especially at the N-type)
- Feed probe dimensions (length and straightness)
- Whether the backshort is making good contact with the waveguide panels

#### A3: Effect of environment

Repeat the measurement in different environments:

1. Outdoors, open field
2. Indoor lab (walls nearby)
3. With and without grounded objects near the aperture

The resonance frequency should not shift by more than a few MHz between environments. Large shifts indicate the antenna is coupling to nearby objects.

#### A4: Final result interpretation

Load your .s1p file and the reference file `5_inside_cleaned_backshort/anten_son_horn.s1p` in the same S-parameter viewer:

```python
import numpy as np
import matplotlib.pyplot as plt

def read_s1p(fname):
    data = np.loadtxt(fname, comments=['!', '#'])
    return data[:, 0], data[:, 1] + 1j * data[:, 2]  # freq, S11 complex

f_ref, s11_ref = read_s1p('measurements/antenna/5_inside_cleaned_backshort/anten_son_horn.s1p')
f_yours, s11_yours = read_s1p('your_measurement.s1p')

plt.figure()
plt.plot(f_ref / 1e9, 20 * np.log10(np.abs(s11_ref)), label='Reference (Mergen-21)')
plt.plot(f_yours / 1e9, 20 * np.log10(np.abs(s11_yours)), label='Your measurement')
plt.xlabel('Frequency (GHz)')
plt.ylabel('S11 (dB)')
plt.axvline(1.420405, color='red', ls='--', label='HI 21 cm')
plt.legend()
plt.grid()
plt.show()
```

---

## Part B: RF Chain S-Parameter Measurement

### Procedure

#### B1: VNA 2-port calibration

1. Perform a full 2-port SOLT calibration over **1.0–2.0 GHz**.
2. Reference planes are at the cable ends that will connect to the chain input (SMA) and output (SMA).

#### B2: Individual component measurement

Measure each component in the chain separately:
- ZX60-P162LN+ (LNA): connect +4 V DC bias before measuring (not 5 V). The LNA requires bias to function.
- ZX75BP-1450-S+ (BPF): passive, no bias needed.
- ZX60-V63+ (Amp): connect the +5 V supply.

For each component, record S11, S21, S12, S22 as a .s2p file.

Compare against the reference files in `measurements/rf-chain/vna/`.

#### B3: Cascaded chain measurement

Connect all three stages in series: LNA → BPF → Amp. Apply DC bias to the two amplifiers.

Measure the cascade S-parameters. Expected results:

| Parameter | Expected value at 1420 MHz |
|---|---|
| S21 (cascade gain) | ≈ +39.5 dB +/- 0.5 dB (VNA has no sample exactly at 1420.405 MHz) |
| S11 (input reflection) | Depends on LNA, typically < −10 dB |

Compare against `measurements/rf-chain/vna/cascade/cascaded chain.s2p`.

---

## Part C: Noise Figure Measurement (Y-Factor Method)

### Background

The noise figure (NF) of a receiver is the degradation in signal-to-noise ratio caused by the receiver itself. For a low-noise radio astronomy receiver, NF should be as low as possible. The cascaded NF is dominated by the first stage (LNA), as predicted by the Friis formula (Lab 1).

The Y-factor method uses a calibrated noise source with known excess noise ratio (ENR) to measure NF directly with a spectrum analyzer.

### Equipment

- Calibrated noise source with known ENR at 1420 MHz (typical ENR: 15–30 dB)
- Spectrum analyzer with noise figure measurement mode (or use power meter and calculate)

### Procedure

#### C1: Cable loss correction

Before measuring the receiver, measure the insertion loss of the cable between the noise source and the DUT:

1. Connect: noise source → cable → spectrum analyzer
2. Measure the analyzer's own NF (with noise source directly connected; no DUT).
3. Insert the cable and measure again. The difference is the cable loss at 1420 MHz.

Use this loss value to correct the DUT noise figure measurement.

Compare against `measurements/rf-chain/nf/cable_loss.DAT`.

#### C2: LNA noise figure

1. Connect: noise source → LNA (biased at +4 V) → spectrum analyzer
2. Set up the spectrum analyzer noise figure measurement at **1420 MHz**, 1 MHz bandwidth.
3. Enter the noise source ENR values.
4. Record the measured NF.

Expected LNA NF: **0.7 dB** (datasheet spec).

#### C3: Cascade noise figure

Connect: noise source → LNA → BPF → Amp → spectrum analyzer

Measure NF as above. Expected: **about 1.5 dB, cable-corrected** (Mergen-21 measured result, obtained with the gain method rather than Y-factor: output noise density of the chain with its input terminated in 50 Ω, minus the 39.5 dB chain gain; see `measurements/rf-chain/nf/README.md` for the cable-loss correction arithmetic).

Compare against files in `measurements/rf-chain/nf/`.

---

## Part D: IP3 Measurement

### Background

The third-order intercept point (IP3) characterizes the linearity of the receiver. A high OIP3 means the receiver tolerates strong interferers without generating intermodulation products that could obscure weak signals.

### Procedure

#### D1: Setup

```
Two-tone source (f1 = 1420.355 MHz, f2 = 1420.455 MHz) ── Attenuator ── DUT ── Spectrum analyzer
```

Mergen-21 used two tones 100 kHz apart around 1420.405 MHz (f1 = 1420.355 MHz, f2 = 1420.455 MHz), which places the IMD3 products at 1420.255 and 1420.555 MHz. A vector signal generator in two-tone mode is the simplest source. If you use two separate generators with a power combiner instead, put 20–30 dB attenuators on the generator outputs to prevent the generators from intermodulating each other.

#### D2: Measurement

1. Set the two-tone input to −12 dBm total (the sum of both tones, i.e. about −15 dBm per tone) at the DUT input. Record the DUT output power at f1 and f2 (fundamental) and at 2f1-f2 and 2f2-f1 (IMD3 products) on the spectrum analyzer.
2. Repeat at −15 dBm and −18 dBm total input.
3. Calculate OIP3:
   - OIP3 = Pout (fundamental) + ΔP / 2
   - where ΔP = Pout(fundamental) − Pout(IMD3) in dB

Expected OIP3 for the cascade: **+29.5 dBm** (output-referred) at −12 dBm total two-tone input (−15 dBm per tone).

Compare raw data against files in `measurements/rf-chain/ip3/`.

---

## Results Summary

When all measurements are complete, fill in this table and compare to the reference:

| Parameter | Simulated | Mergen-21 measured | Your result |
|---|---|---|---|
| Antenna S11 at 1420 MHz (dB) | −19.7 (ideal), −21.8 (worst case) | −41.8 (1420.000 MHz sample, 10 MHz grid) | |
| Antenna resonance frequency (MHz) | 1396 (ideal minimum) | 1420 (10 MHz grid) | |
| Cascade gain (dB) | ~40 | 39.5 +/- 0.5 | |
| Cascade NF (dB) | 0.81 (Friis, VNA gains) | about 1.5 (cable-corrected) | |
| Cascade OIP3 (dBm) | — | +29.5 | |

---

## Data Files Reference

All reference measurement files from the Mergen-21 build are in `measurements/`. Open them with any S-parameter viewer (Qucs, scikit-rf, MATLAB RF Toolbox, or the Python snippet in Part A).

```python
# Load and plot a .s2p file with scikit-rf (pip install scikit-rf)
import skrf as rf
import matplotlib.pyplot as plt

ntwk = rf.Network('measurements/rf-chain/vna/cascade/cascaded chain.s2p')
ntwk.plot_s_db(m=1, n=0)  # S21 in dB
plt.title('Cascaded RF chain gain')
plt.show()
```

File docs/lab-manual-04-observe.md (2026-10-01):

# Lab Manual 4: Observe

**Topic:** Setting up the software receiver, making hydrogen line observations, and analyzing the data  
**Estimated time:** 2 hours (software only with example data) or 4–6 hours (with real hardware)  
**Prerequisites:** Python 3.11+ with the packages in `software/requirements.txt` and Tk (`python3-tk` on Debian/Ubuntu); GNU Radio 3.10+ for live acquisition

---

## Learning Objectives

After completing this lab, students will be able to:

1. Install and run the GNU Radio receiver flowgraph.
2. Configure the ADALM-PLUTO SDR for hydrogen line reception.
3. Record spectral data and verify that 21 cm emission is detected.
4. Use the waterfall viewer to display and interpret the recorded spectra.
5. Identify Doppler-shifted hydrogen emission from different galactic longitudes.
6. Discuss how a calibrated frequency axis would let the observed shift be related to Galactic rotation (future exercise).

---

## Part A: Software Setup (No Hardware Required)

This part uses the example data files already included in the repository. A real antenna or SDR is **not needed** to complete Part A.

### A1: Install Python dependencies

```bash
pip install -r software/requirements.txt
```

This installs: `numpy`, `scipy`, `pandas`, `matplotlib`, `astropy` (the pins require Python 3.11+). The waterfall viewer also needs Tk, which pip does not install (`sudo apt install python3-tk` on Debian/Ubuntu).

### A2: Explore the example data

Example spectra from the Mergen-21 first-light session (2026-04-29, Istanbul, Turkey) are in `observations/data/`. Each `.dat` file is a sequence of float32 power spectra produced by the receiver flowgraph:

```
observations/data/
├── mergen21_spec_20260429_022811.dat   ← early session (settings not recorded)
├── mergen21_spec_20260429_041703.dat   ← later session (settings not recorded)
├── mergen21_spec_20260429_045525_bati.dat    ← pointing west  (Batı = West in Turkish)
├── mergen21_spec_20260429_045857_guney.dat   ← pointing south (Güney = South)
├── mergen21_spec_20260429_050204_doggu.dat   ← pointing east  (Doğu = East)
└── ...
```

Load a single spectrum and display it:

```python
import numpy as np
import matplotlib.pyplot as plt

FFT_SIZE  = 2048
SAMP_RATE = 2_048_000   # samples/second
LO_FREQ   = 1_420_405_000  # Hz (hydrogen line)

# Load the file
raw = np.fromfile('observations/data/mergen21_spec_20260429_041703.dat', dtype=np.float32)

# Each FFT_SIZE values is one spectrum; take the average
n_rows = len(raw) // FFT_SIZE
spectra = raw[:n_rows * FFT_SIZE].reshape(n_rows, FFT_SIZE)
avg = spectra.mean(axis=0)

# Frequency axis (baseband, then shifted to RF)
bb_hz = np.fft.fftshift(np.fft.fftfreq(FFT_SIZE, d=1.0 / SAMP_RATE))
rf_mhz = (LO_FREQ + bb_hz) / 1e6

plt.figure(figsize=(10, 4))
plt.plot(rf_mhz, 10 * np.log10(np.maximum(avg, 1e-30)))
plt.axvline(1420.405751768, color='red', ls='--', label='H I rest frequency')
plt.xlabel('Frequency (MHz)')
plt.ylabel('Power (dB, uncalibrated)')
plt.title('Average spectrum: east pointing, 2026-04-29')
plt.legend()
plt.grid()
plt.tight_layout()
plt.show()
```

**What to look for:** The Galactic H I line appears as a broad hump 80 to 190 kHz above the nominal LO (1420.405 MHz). The narrow spike exactly at the LO is instrumental (the band-center artifact), not hydrogen. The recorded band spans only ±1.024 MHz around the LO.

### A3: Use the interactive waterfall viewer

The waterfall viewer provides a graphical interface for browsing multiple .dat files:

```bash
python software/analysis/mergen21_waterfall_viewer.py
```

In the viewer:
1. Click **Add...** and select one or more `.dat` files from `observations/data/`.
2. Verify that FFT size = 2048, sample rate = 2048000 Hz, LO = 1420405000 Hz.
3. Click **Plot**. The upper panel shows power vs. time (waterfall); the lower panel shows the time-averaged spectrum.
4. Switch the X axis to **Velocity [km/s]** to see the Doppler velocity scale. The nominal LO (the hydrogen rest frequency) maps to 0 km/s; the narrow spike there is the band-center instrumental artifact, and the H I line is the broad hump at about −16 to −36 km/s on this uncorrected topocentric axis.

### A4: Compare east vs. west pointing

Load the east-pointing file (`_doggu` or `_Dogu`) and the west-pointing file (`_bati`) in the same viewer session (use Ctrl+click to select multiple files).

**Discussion questions:**
1. Is the HI emission peak at the same frequency for east and west pointings?
2. If not, what would you need (frequency calibration, LSR correction) before reading the difference as a velocity? (future exercise)
3. Look at the Stellarium sky charts in `observations/stellarium_*.png`. What galactic longitude was the antenna pointing at for each file?

---

## Part B: GNU Radio Receiver Setup (Hardware Required)

This part requires:
- Assembled antenna, LDO board, and RF chain (from Lab 2)
- ADALM-PLUTO SDR connected via USB
- Computer with GNU Radio 3.10+ and the gr-iio / PlutoSDR plugin

### B1: Install GNU Radio

**Ubuntu 22.04 (recommended):**
```bash
sudo apt update
sudo apt install -y gnuradio python3-gi
# Install gr-iio (PlutoSDR driver)
sudo apt install -y gr-iio
```

**Conda (more reliable across distributions):**
```bash
conda create -n gnuradio310 -c conda-forge gnuradio=3.10 gr-iio python=3.11
conda activate gnuradio310
```

Verify installation:
```bash
python3 -c "from gnuradio import gr; print(gr.version())"
gnuradio-companion --version
```

### B2: Connect the hardware

1. Power on the LDO board and verify +4 V on the LNA output and +5 V on the amplifier output.
2. Connect the RF chain: Antenna N-type → SMA cable → LNA input. LNA output → BPF. BPF output → Amp. Amp output → PlutoSDR RX1.
3. Connect the PlutoSDR USB port to the computer.
4. Verify PlutoSDR is detected:
   ```bash
   # Linux
   usb-devices | grep 0456
   # Should show: Vendor=0456 ProdID=b673 (or similar ADALM-PLUTO ID)
   
   # Windows
   iio_info -s
   ```

### B3: Configure the log directory

Before running the flowgraph, set the output directory to a location of your choice. Open `software/gnuradio/receiver.py` and change the `log_dir` variable on approximately line 73:

```python
self.log_dir = log_dir = "logs"   # relative to the directory where you run the script
```

Or provide an absolute path to a directory that already exists on your system. The file sink does not create the directory, so create it first (see B4).

### B4: Launch the receiver

```bash
cd software/gnuradio
mkdir -p logs
python3 receiver.py
```

The flowgraph addresses the Pluto at `ip:192.168.10.1` (`receiver.py:211`). A stock Pluto on USB is `ip:192.168.2.1`, so change `uri` in the Pluto source block.

Or open the flowgraph in GNU Radio Companion:
```bash
gnuradio-companion receiver.grc
```

The GUI shows three panels:
- **RX Quick-Look FFT** (bottom): raw spectrum directly from the PlutoSDR; it confirms RF reception
- **Integrated Power Spectrum** (middle): time-averaged spectrum, updated every ~second
- **Waterfall** (top): historical spectrogram

### B5: Verify reception

With the antenna connected and pointed at the sky:

1. Confirm that noise floor is visible in the Quick-Look FFT panel (flat noise power around −100 to −120 dBm/bin is expected).
2. Confirm that the PlutoSDR is not receiving at its full digital range (saturation appears as a perfectly flat spectrum; if you see this, reduce rx_gain).
3. After 1–2 minutes of integration, a broad emission feature should become visible about 80 to 190 kHz above 1420.405 MHz in the integrated spectrum (the narrow spike exactly at 1420.405 MHz is instrumental). The galactic disk is always above the horizon and produces detectable emission when the beam overlaps it.

### B6: Record an observation

The flowgraph saves data automatically to `logs/` (or whichever directory you configured). File naming: `mergen21_spec_YYYYMMDD_HHMMSS.dat`.

For a useful observation:
1. Note the antenna pointing direction (azimuth and elevation) and current UTC time.
2. Run for at least **5 minutes** per pointing direction to accumulate signal. More integration = better SNR.
3. Move the antenna to a new pointing direction and repeat.

---

## Part C: Analysis: Galactic Rotation Curve (future work)

This part describes a method for a future exercise. It has not been carried out on the released Mergen-21 dataset: rotation-curve extraction needs frequency-axis verification, oscillator calibration, and pointing records that are not yet in place. See `docs/analysis/PROVENANCE_ADDENDUM.md` for what the April 2026 session's data currently supports (pointing-dependent line detections; not a rotation curve).

### Background

The hydrogen 21 cm emission line is produced by cold neutral hydrogen clouds throughout the Milky Way disk. Clouds moving toward or away from Earth produce Doppler-shifted emission. By observing along different galactic longitudes, you can reconstruct the rotation speed of the Galaxy at different distances from the center.

### C1: Velocity calculation

The Doppler formula:

$$v = c \cdot \frac{f_{\rm rest} - f_{\rm obs}}{f_{\rm rest}}$$

where:
- c = 299 792.458 km/s
- f_rest = 1 420 405 751.768 Hz (HI rest frequency)
- f_obs = observed frequency of the emission peak

A positive velocity means the cloud is receding (redshift); negative means approaching.

### C2: Tangent-point method

For a galactic longitude l (between 0° and 90°, northern galactic disk), the highest-velocity emission component comes from the tangent point, the point along the line of sight where the observer, the galactic center, and the cloud are aligned. At this point, all of the cloud's velocity is radial.

Rotation speed at the tangent point:

$$v_{\rm rot}(R_{\rm tan}) = v_{\rm max}(l) + v_\odot \sin(l)$$

where v_max is the maximum observed Doppler velocity at longitude l, and v_⊙ ≈ 220 km/s is the Sun's rotation speed. The tangent point radius is R_tan = R_⊙ sin(l) (R_⊙ ≈ 8.5 kpc).

### C3: Comparing east and west observations

At the latitude of Istanbul (41°N), the galactic plane passes through a range of azimuth angles during the night. The Stellarium screenshots in `observations/` document the galactic longitudes observed during the 2026-04-29 session.

Load the directional files (east/west/south) in the viewer and measure the velocity of the most redshifted or blueshifted peak in each spectrum. Plot rotation speed vs. galactocentric radius.

---

## Synthesizer Flowgraphs (Hardware-Free GNU Radio Test)

If you have GNU Radio installed but no PlutoSDR, the `21cm synth/` flowgraphs generate synthetic HI data through the full signal-processing chain:

| Flowgraph | What it generates |
|---|---|
| `topo1_cw_tone.grc` | Single continuous-wave tone at 1420.405 MHz |
| `topo2_single_gaussian.grc` | Single Gaussian spectral line (one HI cloud) |
| `topo3_galaxy_rotation.grc` | Multiple Gaussian components (realistic galactic spectrum) |

To run:
```bash
cd software/gnuradio
gnuradio-companion "21cm synth/topo3_galaxy_rotation.grc"
```

These flowgraphs use a signal source block instead of a PlutoSDR source, so they run entirely in software. They verify that GNU Radio, the FFT integrator, and the display blocks work correctly before connecting real hardware.

---

## Expected Observation Results

From the Istanbul site (41.0°N, 29.0°E), galactic HI emission is detectable in most pointing directions. The released line fits from the 2026-04-29 session are:

| Pointing | File | Peak excess | Centroid above nominal LO | FWHM |
|---|---|---|---|---|
| South | `_guney` | 18.13 % | 172.1 kHz | 77.2 kHz |
| East | `_doggu` | 7.87 % | 138.5 kHz | 88.9 kHz |
| West | `_bati` | 5.45 % | 77.8 kHz | 151.9 kHz |

Velocities are not quoted, because the frequency axis is not calibrated (see `docs/analysis/PROVENANCE_ADDENDUM.md`).

Plots in `observations/plots/` show the spectra from this session.

---

## Troubleshooting

**No signal visible in Quick-Look FFT:** Verify USB cable, try a different USB port, and confirm `iio_info -s` detects the PlutoSDR.

**Flat spectrum (saturation):** Reduce SDR gain to 0 dB, then increase slowly while monitoring the noise floor.

**No HI emission visible after long integration:** Confirm the antenna is pointing at the sky (not a nearby wall or the ground). The galactic plane transits the meridian at LST equal to the right ascension of the target; check a planetarium app.

**Viewer crashes or freezes:** Each .dat file can be several hundred MB. The viewer uses memory-mapping and will decimate to at most 2500 display rows. If problems persist, try loading a single small file first.

**gr-iio not found:** On Ubuntu/conda, ensure the PlutoSDR plugin is installed (package `gr-iio`). On Windows, the PlutoSDR driver and libiio must be installed separately from the Analog Devices website.

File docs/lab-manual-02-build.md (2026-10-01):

# Lab Manual 2: Build

**Topic:** Fabricating and assembling the Mergen-21 horn antenna and LDO power supply  
**Estimated time:** 4–6 hours (plus external fabrication lead time)  
**Prerequisites:** Basic hand-tool skills; access to a laser or waterjet cutting service; soldering capability

---

## Learning Objectives

After completing this lab, students will be able to:

1. Prepare DXF files for laser or waterjet cutting of sheet-metal antenna panels.
2. Assemble a pyramidal horn antenna from flat sheet-metal parts.
3. Fabricate a waveguide-to-coax transition using a standard N-type connector.
4. Solder the probe feed element and verify continuity.
5. Order a simple two-layer PCB from a fabrication service using Gerber files.

---

## Safety Notes

- **Laser cutting:** Wear appropriate eye protection. All cuts generate aluminum dust; use a filtered mask and ensure adequate ventilation.
- **Soldering:** Work in a ventilated area. Allow the soldering iron and workpiece to cool before handling.
- **Sheet metal edges:** Cut aluminum edges are sharp. Deburr all edges with a file or sandpaper before handling.

---

## Part A: Horn Antenna Fabrication

### Files Needed

| File | Location | Purpose |
|---|---|---|
| E-plane DXF | `hardware/antenna/dxf/eplane_v0.3.dxf` | Laser cutting template |
| H-plane DXF | `hardware/antenna/dxf/hplane_v0.3.dxf` | Laser cutting template |
| Backshort DXF | `hardware/antenna/dxf/backshort_0.1.dxf` | Laser cutting template |
| Waveguide DXF | `hardware/antenna/dxf/wave_0.1.dxf` | Laser cutting template |
| E-plane drawing (PDF) | `hardware/antenna/drawings/eplane_v0.3.pdf` | Dimensioned reference |
| H-plane drawing (PDF) | `hardware/antenna/drawings/hplane_v0.3.pdf` | Dimensioned reference |
| Backshort drawing (PDF) | `hardware/antenna/drawings/backshort_0.1-1.pdf` | Dimensioned reference |
| Waveguide drawing (PDF) | `hardware/antenna/drawings/wave_0.1.pdf` | Dimensioned reference |
| Assembly instructions | `hardware/antenna/ASSEMBLY.md` | Step-by-step assembly |

### Materials

| Item | Specification | Quantity |
|---|---|---|
| Aluminum sheet | Alloy 5754-H22, 1.5 mm thick | Enough for the four flat patterns (DXF extents): E-plane panel 719 × 682 mm, H-plane panel 638 × 572 mm, waveguide 312 × 507 mm, backshort 183 × 103 mm |
| N-type female chassis connector | Amphenol RF 000-49000-SRFX (or equivalent) | 1 |
| Copper wire | 1.0 mm diameter, bare (not insulated) | ~50 mm |
| M3 × 30 mm bolts (DIN 965TX, stainless A2-304) | — | See note below |
| M3 × 8 mm bolts (DIN 7985TX, stainless A2-304) | — | See note below |
| M3 flat washers (DIN 125, stainless) | — | See note below |
| M3 spring washers (DIN 127, stainless) | — | See note below |
| M3 hex nuts (DIN 934, stainless A2-304) | — | See note below |

**Fastener count:** count the holes in the DXF files. They carry 198 bolt holes in total: `eplane_v0.3.dxf` 44, `hplane_v0.3.dxf` 48, `backshort_0.1.dxf` 24 and `wave_0.1.dxf` 82 (plus one 16.3 mm connector hole). Where a bolt clamps two overlapping holes, expect roughly half as many bolts as holes (about 100), with one nut and one spring washer per bolt. Buy spares. Extents assume the DXF units are mm (`$INSUNITS` = 4 in all four files).

### Procedure

#### A1: Order laser-cut parts

Send the four DXF files in `hardware/antenna/dxf/` to a sheet-metal fabrication service with the following instructions:

- **Material:** Aluminum alloy 5754-H22, **1.5 mm thick** (not thicker; the tolerance stack matters for the waveguide fit)
- **Process:** Laser or waterjet cutting
- **Flatness:** ≤ 0.5 mm deviation over any 200 mm span; specify this explicitly. Poor flatness is the most common problem.
- **Bending (if applicable):** The waveguide and backshort parts may require bending. Provide PDF drawings with explicit bend angles. **Verify angles with the shop before production**; the original build encountered 90° bending errors.

> **Tolerance note:** The DXF files encode the nominal geometry. The backshort-to-probe distance is the most sensitive dimension (affects resonance frequency). Allow ±0.5 mm on this dimension; all other dimensions can be ±1 mm.

Allow **5–10 business days** for cutting and shipping.

#### A2: Prepare the N-type connector and feed probe

While waiting for parts:

1. Cut a 38 mm length of 1.0 mm copper wire. The wire must be **pure copper** (not copper-clad steel) and completely bare (no insulation).
2. Tin the inner contact of the N-type connector with a small amount of solder.
3. Solder the copper wire perpendicular to the connector contact, centered and straight.
4. Inspect under magnification: the joint must be shiny and mechanically rigid. A cold or cracked joint will cause poor S11.
5. Allow to cool. Do not bend the wire after soldering.

#### A3: Deburr and inspect parts

When parts arrive:

1. Inspect each panel for flatness using a steel straightedge. Reject panels with more than 0.5 mm deviation.
2. Deburr all cut edges with a fine file or 320-grit sandpaper. Remove any sharp burrs around bolt holes.
3. Check that bolt holes are clean and correctly positioned; compare to the PDF drawings.

#### A4: Mechanical assembly

Follow the step-by-step instructions in `hardware/antenna/ASSEMBLY.md`. Key points:

- Use M3×30 bolts initially to align panels, then swap to M3×8 bolts for final tightening.
- Tighten in a cross-pattern. Recommended torque: 0.5–1.0 Nm (finger-tight plus ~1/8 turn).
- Install the N-type connector and feed probe **last**, after the outer structure is assembled.
- **Check the feed probe depth** against the drawing (`backshort_0.1-1.pdf`). The probe depth above the waveguide floor is a critical dimension.

#### A5: Visual inspection before electrical test

Before any RF measurement, verify:

- [ ] All panels are flush with no visible gaps at seams
- [ ] Feed probe is vertical and centered in the waveguide aperture
- [ ] N-type connector body is fully seated and the retaining nut is tight
- [ ] No metal chips or debris inside the waveguide (use a torch and mirror to inspect)
- [ ] The center conductor of the N-type connector is not shorted to the body (check with a multimeter; it should be open circuit, not 0 Ω)

---

## Part B: LDO Power Supply Board

The LDO board provides clean, low-noise DC power to the two RF amplifiers (ZX60-P162LN+ and ZX60-V63+). The ZX60-P162LN+ LNA needs +4 V and the ZX60-V63+ amplifier +5 V; the regulator board supplies both rails from a common 5.5 V input. Do not connect the LNA to 5 V. The board uses two TPS7A4701RGWT ultra-low-noise LDO regulators.

### Files Needed

| File | Location |
|---|---|
| Gerber files (PCB fabrication) | `hardware/ldo-regulator/gerbers/` |
| Pick-and-place file | `hardware/ldo-regulator/pick-and-place/Pick Place for PCB1.txt` |
| Bill of materials | `hardware/ldo-regulator/bom.pdf` |
| Schematic | `hardware/ldo-regulator/schematic.pdf` |
| PCB layout | `hardware/ldo-regulator/pcb.pdf` |
| 3D STEP model (mechanical reference) | `hardware/ldo-regulator/PCB1.step` |

### Procedure

#### B1: Order the PCB

Send the entire contents of `hardware/ldo-regulator/gerbers/` to a PCB fabrication service (JLC PCB, OSH Park, PCBWay, etc.) with the following specification:

- **Layers:** 2 (double-sided)
- **Thickness:** 1.6 mm FR4
- **Copper weight:** 1 oz
- **Surface finish:** HASL or ENIG
- **Color:** Any (green is cheapest)

Allow 5–10 business days for fabrication and shipping. Cost is typically $15–30 for 5 boards.

#### B2: Assemble the board

Components are listed in `bom.pdf`. Use the pick-and-place file as a reference for component positions.

1. Apply solder paste to all SMD pads using a stencil or manually.
2. Place the TPS7A4701RGWT ICs first (they are QFN packages; use tweezers and a microscope or magnifier).
3. Place passive components (resistors, capacitors).
4. Reflow-solder (preferred) or hand-solder with a fine-tip iron.
5. Inspect all joints under magnification.

#### B3: Initial power-on and verification

Before connecting any RF components:

1. Set a bench power supply to 7–12 V input (within the TPS7A4701RGWT input range).
2. Connect to the board input with current limiting set to 100 mA.
3. Power on and verify:
   - Input current should be < 20 mA at no load
   - Output voltage should be 5.0 V ±0.1 V at each output
   - No excessive heat from any component

If the output voltage is incorrect, check the resistor divider values against `schematic.pdf`. The TPS7A4701 output is set by an external resistor network.

---

## Mechanical Tolerances

These are the critical dimensions and their allowed deviations, derived from the simulation tolerance study (see `hardware/simulation/cst/assembly_worstcase/`):

| Dimension | Nominal | Max allowed deviation | Effect of exceedance |
|---|---|---|---|
| Backshort-to-probe distance | Per drawing | ±0.5 mm | Shifts resonance frequency, degrades S11 |
| Probe wire length above waveguide floor | 38 mm | ±0.5 mm | Changes coupling depth, affects S11 depth |
| Panel flatness | 0 mm deflection | ±0.5 mm over 200 mm | Gap-induced current leakage, pattern distortion |
| Panel seam gaps | 0 mm | <0.3 mm | Allows RF leakage at seams |
| Aluminum sheet thickness | 1.5 mm | ±0.1 mm | Affects internal waveguide dimensions |
| Bolt hole diameter | 3.4 mm as drawn (r = 1.7 mm; four holes in `wave_0.1.dxf` are 3.2 mm) | ±0.1 mm | If too large, panel alignment is poor |

**The most consequential dimensions** are the probe depth and backshort distance. These directly control the impedance matching at 1420 MHz. If S11 is worse than −15 dB, start by checking these two.

---

## Common Problems and Solutions

| Problem | Likely Cause | Solution |
|---|---|---|
| S11 poor (> −10 dB) at 1420 MHz | Probe depth or backshort incorrect | Re-measure probe length; compare to drawings |
| S11 resonance is offset in frequency | Sheet thickness different from 1.5 mm | Check material spec; re-order if needed |
| Antenna feels mechanically unstable | Bolts undertightened or wrong size | Re-tighten in cross-pattern; verify M3 specification |
| LDO board output is wrong voltage | Wrong resistor values | Check schematic, verify with ohmmeter before soldering |
| Feed probe shorts to waveguide body | Wire bent during assembly | Straighten probe; verify clearance with multimeter |

---

## Next Steps

After successfully assembling and visually inspecting the antenna and LDO board, proceed to **Lab 3: Measure** to characterize the antenna S11 and RF chain performance with a VNA.

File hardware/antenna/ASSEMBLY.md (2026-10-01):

# Mergen-21 Antenna Assembly Guide

## Overview

This document provides complete assembly instructions for the Mergen-21 antenna. The assembly involves soldering the copper feed element to the N-type connector, followed by mechanical fastening of the antenna structure using M3 bolts with spring washers and nuts.

**Antenna Material:** Aluminum 5754, 1.5 mm thickness
**Waveguide seam:** The long waveguide seam lies on a 160 mm (broad) wall.
**Waveguides:** Flat patterns in [`dxf/wave_0.1.dxf`](dxf/wave_0.1.dxf) (waveguide) and [`dxf/backshort_0.1.dxf`](dxf/backshort_0.1.dxf) (backshort)
**Assembly Status:** Field-tested with documented manufacturing challenges (see Notes section)

---

## Tools Required

- Soldering iron (for initial copper wire attachment)
- Lighter or heat source (for isolation removal)
- 5.5 mm wrench/socket (M3 nut size) - **Note: difficult to source, consider M4 for future designs**
- Screwdriver (for bolt head if needed)
- Hammer (for straightening bent waveguide connectors, if needed)
- Measuring tape or calipers
- Safety glasses

---

## Bill of Materials (BOM)

### Connectors & Electrical Components

| Part | Description | Qty | DIN/Spec | Supplier | Notes |
|---|---|-----|---|---|---|
| N-Type Connector | Amphenol RF 000-49000-SRFX | 1 | - | [Digikey](https://www.digikey.com/en/products/detail/amphenol-rf/000-49000-SRFX/4746416) | Main feed point |
| Copper Wire | 1.0 mm diameter, 38 mm length | 1 | - | Local/Supplier | Pure copper recommended |

### Fastening Components

| Part | Description | Qty | DIN | Material | Supplier |
|---|---|-----|-----|---|---|
| Bolt (Long) | M3 × 30 mm | 8-12 | DIN 965TX | Stainless Steel A2-304 | Local hardware store |
| Bolt (Final) | M3 × 8 mm | 8-12 | DIN 7985TX | Stainless Steel A2-304 | Local hardware store |
| Washer (Flat) | M3 flat washer | 8-12 | DIN 125 | Stainless Steel | Local hardware store |
| Spring Washer | M3 spring washer | 8-12 | DIN 127 | Stainless Steel | Local hardware store |
| Nut | M3 hex nut | 8-12 | DIN 934 A2-304 | Stainless Steel | Local hardware store |

**Note:** Exact quantity depends on antenna size and number of bolt holes. Count bolt holes in drawings and adjust accordingly.

### Structural Component

| Part | Description | Qty | Specification | Notes |
|---|---|-----|---|---|
| Aluminum Sheet | Antenna body | 1 | 5754-H22, 1.5 mm thickness | See warnings about material quality |

---

## Assembly Sequence

### Phase 1: Feed Element Preparation

1. **Solder copper wire to N-type connector**
   - Prepare the copper wire: 1.0 mm diameter, 38 mm length
   - Clean the N-type connector solder point with flux
   - Solder the copper wire perpendicular to the connector contact point
   - Allow solder joint to cool completely
   - **Inspect:** Solder joint should be shiny and crack-free

2. **Remove wire insulation**
   - Carefully burn off all remaining insulation using a lighter
   - Work slowly to avoid damaging the copper wire
   - The wire should be bare copper after this step
   - Allow to cool

3. **Final inspection**
   - Verify copper wire is straight and properly soldered
   - Check that no insulation remains
   - Confirm wire dimensions: 1.0 mm diameter, ~38 mm length

**Figure 1.1:** N-type connector with soldered copper feed element
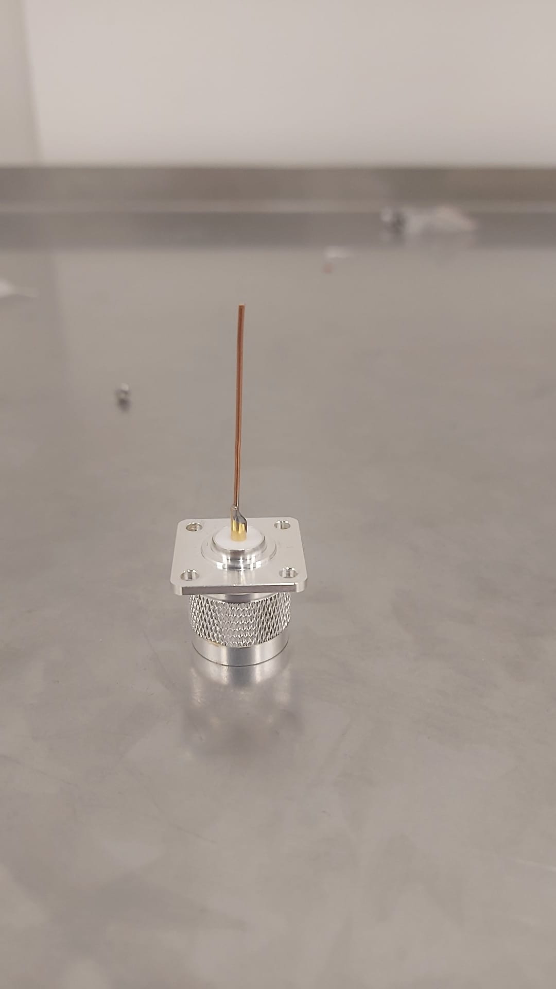
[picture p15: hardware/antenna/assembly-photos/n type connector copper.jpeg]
N-type connector with copper feed


---

### Phase 2: Mechanical Assembly - Bolt Installation

#### Step 1: Initial Bolting with M3×30 Bolts

1. Insert M3×30 bolts into bolt holes (starting with multiple holes simultaneously)
2. For each bolt hole, assemble in this order (from antenna surface inward):
   - Bolt head (outside antenna)
   - Flat washer (DIN 125)
   - Spring washer (DIN 127)
   - Aluminum antenna wall
   - Aluminum antenna wall (second layer if applicable)
   - Nut (inside antenna) - **Note: nuts remain inside**

3. Thread approximately 4-6 bolts loosely - do not fully tighten yet
4. These long bolts serve as initial alignment and holding points

#### Step 2: Transition to M3×8 Bolts

1. Once initial long bolts are in place and holding the structure:
   - Remove one M3×30 bolt
   - Replace with M3×8 bolt (same washer stack configuration)
   - Repeat for remaining bolts in a cross-pattern (to maintain even pressure)

2. Replace all M3×30 bolts with M3×8 bolts in this sequence:
   - This prevents distortion of the antenna structure
   - Ensures even clamping pressure

#### Step 3: Final Tightening

1. Once all bolts are M3×8, perform final tightening
2. Tighten in a cross-pattern (opposite sides alternately)
3. Do not over-tighten - stop when resistance is felt
   - **Recommended torque:** 0.5-1.0 Nm (if torque wrench available)

#### Step 4: Installation of N-Type Connector and Feed

1. Mount the prepared N-type connector with soldered copper feed element
2. Secure to antenna according to connector mounting design
3. Verify copper feed element is aligned with antenna aperture

**Figure 2.1:** Horn antenna assembly showing bolt pattern and N-type connector integration
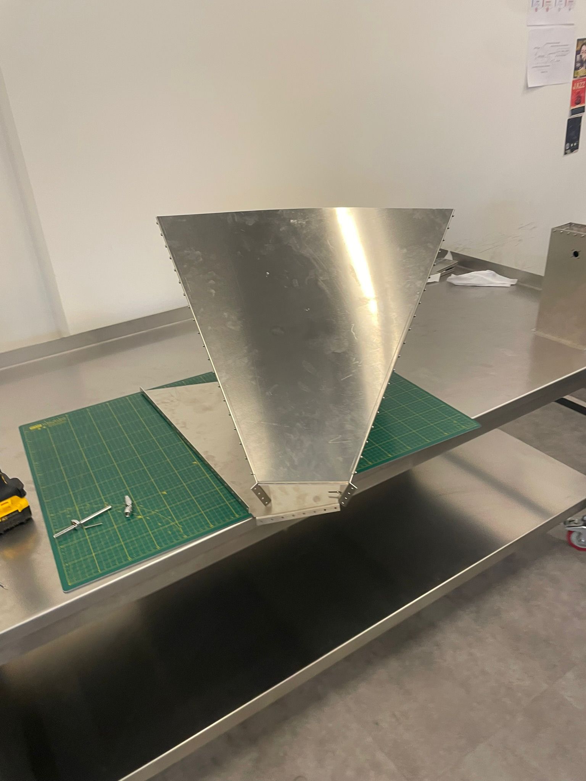
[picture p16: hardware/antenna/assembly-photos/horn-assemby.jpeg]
Horn antenna assembly


**Figure 2.2:** Finished horn with N-type waveguide connector
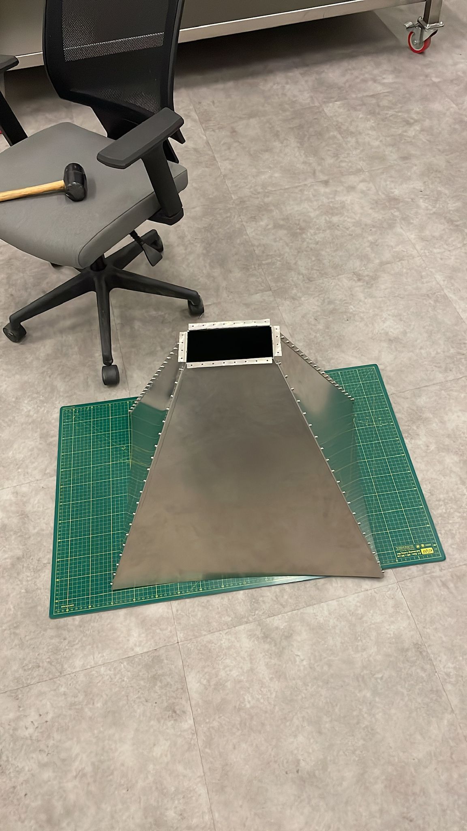
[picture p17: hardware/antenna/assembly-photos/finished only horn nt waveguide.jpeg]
Finished horn with N-type connector


---

## Assembly Notes & Warnings

### ⚠️ Manufacturing Issues Encountered

During assembly of this antenna, the following manufacturing challenges were documented:

**Figure 3.1:** Laser cutting equipment used for antenna components
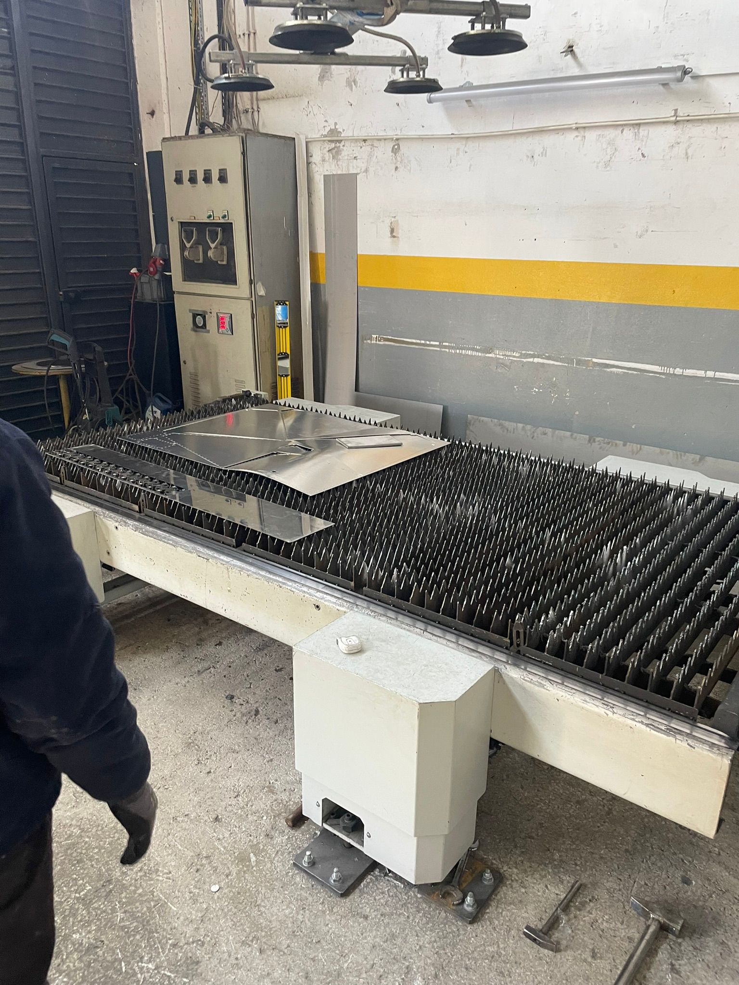
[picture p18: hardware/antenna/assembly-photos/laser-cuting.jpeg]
Laser cutting machine


**Figure 3.2:** All antenna parts after laser cutting and bending
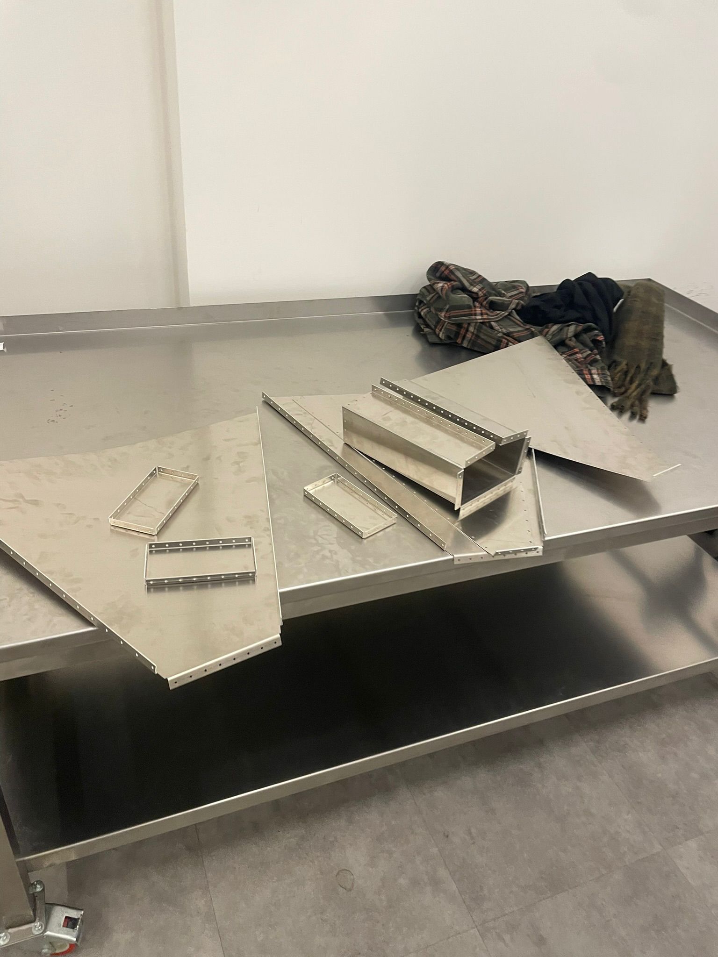
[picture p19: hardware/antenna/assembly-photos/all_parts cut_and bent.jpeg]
All parts cut and bent


1. **Waveguide Bending Problem**
   - Issue: Laser cutting and bending service misunderstood specifications
   - Result: H-plane and E-plane waveguide connectors were bent 90° less than specified
   - Solution: Straightened connectors using a hammer
   - Lesson: Verify bending angles with manufacturer before production
   - **Recommendation for next design:** Provide detailed bending diagrams and angle tolerances

2. **Aluminum Material Quality**
   - Issue: Supplier provided aluminum sheet with slight concave deformation
   - Cause: Not determined
   - Impact: Caused assembly misalignment and uneven bolt clamping
   - **Recommendation:** Specify material flatness tolerance (±0.5 mm over 200 mm) and request surface verification

### ⚠️ Assembly Best Practices

1. **Wrench Size Issue**
   - M3 nuts require 5.5 mm wrench - this is **difficult to source**
   - Many standard wrench sets do not include 5.5 mm size
   - **For next iteration:** Consider upgrading to M4 bolts and nuts (common 6 mm wrench readily available)

2. **Spring Washer Orientation**
   - Always place spring washer AFTER flat washer (next to bolt head)
   - This protects the antenna surface from spring washer edge marks

3. **Nut Access**
   - Design accounts for nuts remaining inside antenna
   - Ensure adequate interior access before assembly
   - Do not over-tighten - stainless steel can seize if forced

4. **Material Flatness Check**
   - Before assembly, verify aluminum sheet is flat using straightedge
   - If material is warped, address before bolting (pressing/hammering if necessary)

---

## Recommended Design Improvements for Next Iteration

Based on assembly experience, the following modifications are recommended:

1. **Upgrade to M4 Fasteners**
   - Use M4×30 and M4×8 bolts instead of M3
   - Use DIN 934 M4 nuts and DIN 125 M4 washers
   - Reason: 6 mm wrench is standard and widely available; 5.5 mm is not
   - Benefit: Easier assembly and maintenance by end-users

2. **Material Specifications**
   - Tighten aluminum flatness tolerance to ±0.5 mm maximum deviation
   - Request surface inspection report from supplier
   - Consider sourcing from dedicated aerospace-grade supplier
   - Confirm material is aluminum 5754-H22 with a mill certificate

3. **Manufacturing Process**
   - Provide detailed bending diagrams with angle tolerances (±1° maximum)
   - Request prototype verification before full production run
   - Include flatness check in final inspection

4. **Assembly Documentation**
   - Provide detailed assembly drawings with cross-sections
   - Include torque specifications for final assembly
   - Add photos of correct bolt orientation and washer stacking order

---

## Finished Assembly

The completed antenna after full assembly and testing:

**Figure 4.1:** Finished antenna - front view
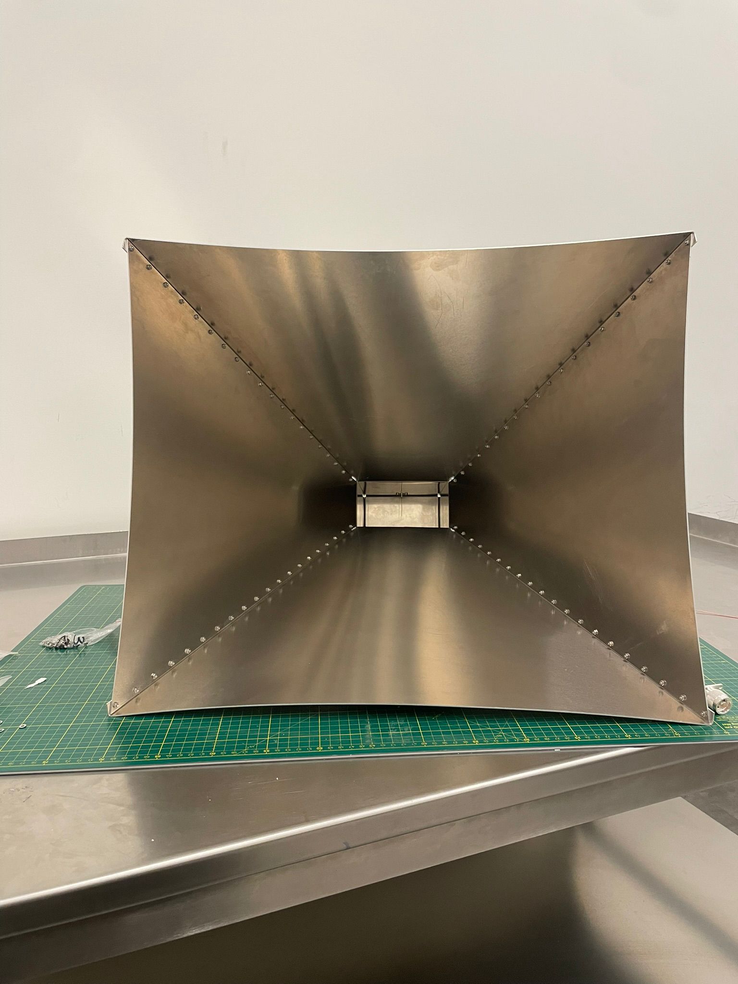
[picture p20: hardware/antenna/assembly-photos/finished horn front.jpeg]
Finished horn front view


**Figure 4.2:** Finished antenna - side profile
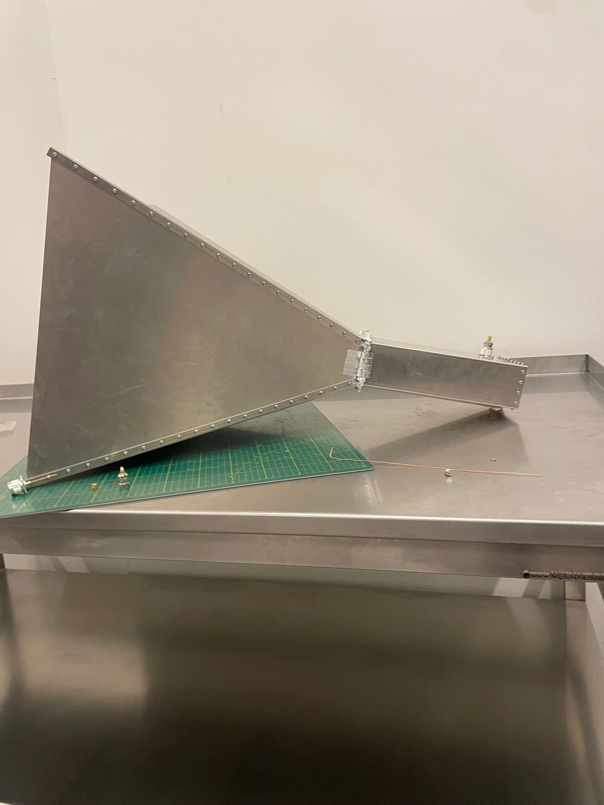
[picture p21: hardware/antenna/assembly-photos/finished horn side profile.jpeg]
Finished horn side profile


**Figure 4.3:** Finished assembly with scale reference (banana for size comparison)
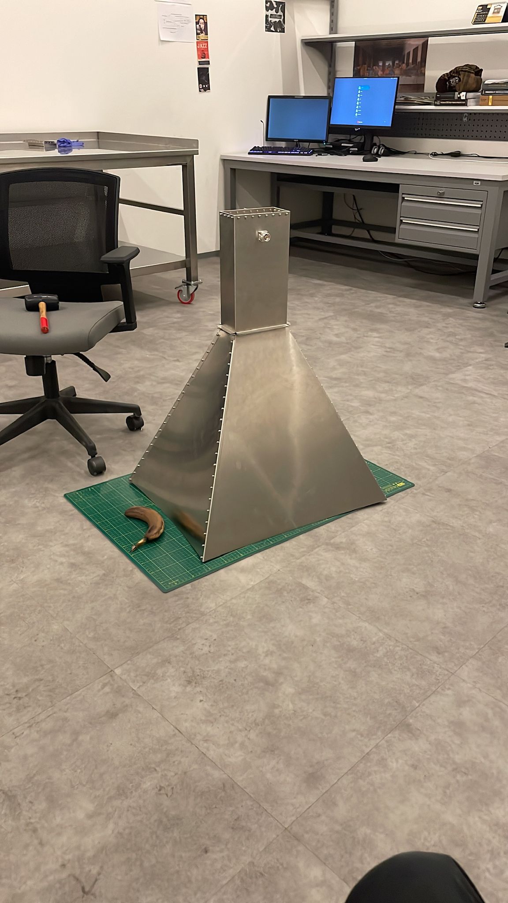
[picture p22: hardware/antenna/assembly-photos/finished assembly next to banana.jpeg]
Finished assembly with banana scale


---

## Storage & Maintenance

- Store bolts, washers, and nuts in anti-corrosion bags (they are stainless steel A2-304)
- Keep spare fasteners for field repairs (recommend 10-20% spare quantity)
- If assembly requires disassembly: remove bolts in reverse cross-pattern to prevent distortion

---

## References

- DIN 125: Flat washers
- DIN 127: Spring (lock) washers
- DIN 934: Hexagon nuts
- DIN 7985TX: Phillips pan head screws (used as bolts)
- DIN 965TX: Phillips countersunk bolts
- N-Type Connector: Amphenol RF 000-49000-SRFX
- Aluminum: EN 5754-H22 (AlMg3 alloy)

---

## Revision History

| Date | Version | Changes |
|---|---|---|
| 2026-03-29 | 1.1 | Added assembly photos and visual documentation |
| 2026-03-29 | 1.0 | Initial documentation with DIN specifications and assembly sequence |

---

**Document Author:** Mergen-21 Project
**Last Updated:** 2026-03-29
**Status:** Complete with manufacturing notes and photo documentation
**Assembly Photos:** 8 photos included in `assembly-photos/` folder

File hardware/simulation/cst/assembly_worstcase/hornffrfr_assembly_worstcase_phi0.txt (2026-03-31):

Theta [deg.]  Phi   [deg.]  Abs(Dir.)[dBi   ]   Abs(Theta)[dBi   ]  Phase(Theta)[deg.]  Abs(Phi  )[dBi   ]  Phase(Phi  )[deg.]  Ax.Ratio[dB    ]    
------------------------------------------------------------------------------------------------------------------------------------------------------
   0.000           0.000            1.690e+01           1.690e+01             234.914          -4.871e+01             217.719           4.000e+01     
   1.000           0.000            1.688e+01           1.688e+01             234.879          -4.917e+01             218.768           4.000e+01     
   2.000           0.000            1.681e+01           1.681e+01             234.805          -4.967e+01             219.842           4.000e+01     
   3.000           0.000            1.668e+01           1.668e+01             234.697          -5.020e+01             221.007           4.000e+01     
   4.000           0.000            1.651e+01           1.651e+01             234.561          -5.076e+01             222.338           4.000e+01     
   5.000           0.000            1.629e+01           1.629e+01             234.409          -5.134e+01             223.917           4.000e+01     
   6.000           0.000            1.602e+01           1.602e+01             234.254          -5.193e+01             225.827           4.000e+01     
   7.000           0.000            1.570e+01           1.570e+01             234.116          -5.251e+01             228.141           4.000e+01     
   8.000           0.000            1.534e+01           1.534e+01             234.017          -5.305e+01             230.913           4.000e+01     
   9.000           0.000            1.492e+01           1.492e+01             233.985          -5.354e+01             234.152           4.000e+01     
  10.000           0.000            1.446e+01           1.446e+01             234.054          -5.395e+01             237.802           4.000e+01     
  11.000           0.000            1.395e+01           1.395e+01             234.261          -5.425e+01             241.728           4.000e+01     
  12.000           0.000            1.340e+01           1.340e+01             234.652          -5.443e+01             245.719           4.000e+01     
  13.000           0.000            1.283e+01           1.283e+01             235.273          -5.448e+01             249.524           4.000e+01     
  14.000           0.000            1.222e+01           1.222e+01             236.174          -5.441e+01             252.895           4.000e+01     
  15.000           0.000            1.160e+01           1.160e+01             237.401          -5.426e+01             255.636           4.000e+01     
  16.000           0.000            1.098e+01           1.098e+01             238.987          -5.404e+01             257.626           4.000e+01     
  17.000           0.000            1.039e+01           1.039e+01             240.939          -5.380e+01             258.812           4.000e+01     
  18.000           0.000            9.832e+00           9.832e+00             243.230          -5.355e+01             259.192           4.000e+01     
  19.000           0.000            9.340e+00           9.340e+00             245.779          -5.332e+01             258.797           4.000e+01     
  20.000           0.000            8.931e+00           8.931e+00             248.452          -5.311e+01             257.674           4.000e+01     
  21.000           0.000            8.615e+00           8.615e+00             251.070          -5.295e+01             255.873           4.000e+01     
  22.000           0.000            8.394e+00           8.394e+00             253.434          -5.284e+01             253.439           4.000e+01     
  23.000           0.000            8.257e+00           8.257e+00             255.359          -5.277e+01             250.418           4.000e+01     
  24.000           0.000            8.189e+00           8.189e+00             256.703          -5.275e+01             246.850           4.000e+01     
  25.000           0.000            8.166e+00           8.166e+00             257.377          -5.278e+01             242.772           4.000e+01     
  26.000           0.000            8.167e+00           8.167e+00             257.346          -5.285e+01             238.224           4.000e+01     
  27.000           0.000            8.172e+00           8.172e+00             256.614          -5.297e+01             233.242           4.000e+01     
  28.000           0.000            8.166e+00           8.166e+00             255.218          -5.313e+01             227.868           4.000e+01     
  29.000           0.000            8.136e+00           8.136e+00             253.206          -5.333e+01             222.145           4.000e+01     
  30.000           0.000            8.073e+00           8.073e+00             250.636          -5.356e+01             216.121           4.000e+01     
  31.000           0.000            7.971e+00           7.971e+00             247.566          -5.383e+01             209.847           4.000e+01     
  32.000           0.000            7.825e+00           7.825e+00             244.054          -5.413e+01             203.375           4.000e+01     
  33.000           0.000            7.631e+00           7.631e+00             240.154          -5.448e+01             196.764           4.000e+01     
  34.000           0.000            7.388e+00           7.388e+00             235.919          -5.486e+01             190.077           4.000e+01     
  35.000           0.000            7.094e+00           7.094e+00             231.402          -5.529e+01             183.384           4.000e+01     
  36.000           0.000            6.746e+00           6.746e+00             226.651          -5.577e+01             176.763           4.000e+01     
  37.000           0.000            6.344e+00           6.344e+00             221.718          -5.630e+01             170.309           4.000e+01     
  38.000           0.000            5.884e+00           5.884e+00             216.658          -5.690e+01             164.134           4.000e+01     
  39.000           0.000            5.365e+00           5.365e+00             211.529          -5.758e+01             158.376           4.000e+01     
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

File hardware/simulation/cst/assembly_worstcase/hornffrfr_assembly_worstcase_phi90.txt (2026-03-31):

Theta [deg.]  Phi   [deg.]  Abs(Dir.)[dBi   ]   Abs(Theta)[dBi   ]  Phase(Theta)[deg.]  Abs(Phi  )[dBi   ]  Phase(Phi  )[deg.]  Ax.Ratio[dB    ]    
------------------------------------------------------------------------------------------------------------------------------------------------------
   0.000          90.000            1.690e+01          -4.871e+01             217.719           1.690e+01              54.914           4.000e+01     
   1.000          90.000            1.688e+01          -4.904e+01             225.640           1.688e+01              54.866           4.000e+01     
   2.000          90.000            1.682e+01          -4.917e+01             233.954           1.682e+01              54.714           4.000e+01     
   3.000          90.000            1.673e+01          -4.909e+01             242.007           1.673e+01              54.461           4.000e+01     
   4.000          90.000            1.659e+01          -4.886e+01             249.197           1.659e+01              54.108           4.000e+01     
   5.000          90.000            1.642e+01          -4.852e+01             255.144           1.642e+01              53.660           4.000e+01     
   6.000          90.000            1.621e+01          -4.816e+01             259.711           1.621e+01              53.119           4.000e+01     
   7.000          90.000            1.596e+01          -4.783e+01             262.924           1.596e+01              52.492           4.000e+01     
   8.000          90.000            1.567e+01          -4.759e+01             264.880           1.567e+01              51.783           4.000e+01     
   9.000          90.000            1.535e+01          -4.745e+01             265.682           1.535e+01              51.002           4.000e+01     
  10.000          90.000            1.499e+01          -4.743e+01             265.399           1.499e+01              50.155           4.000e+01     
  11.000          90.000            1.459e+01          -4.755e+01             264.050           1.459e+01              49.252           4.000e+01     
  12.000          90.000            1.416e+01          -4.781e+01             261.593           1.416e+01              48.305           4.000e+01     
  13.000          90.000            1.369e+01          -4.820e+01             257.920           1.369e+01              47.324           4.000e+01     
  14.000          90.000            1.319e+01          -4.872e+01             252.841           1.319e+01              46.322           4.000e+01     
  15.000          90.000            1.265e+01          -4.933e+01             246.099           1.265e+01              45.314           4.000e+01     
  16.000          90.000            1.209e+01          -4.997e+01             237.419           1.209e+01              44.313           4.000e+01     
  17.000          90.000            1.149e+01          -5.054e+01             226.654           1.149e+01              43.334           4.000e+01     
  18.000          90.000            1.087e+01          -5.090e+01             214.070           1.087e+01              42.392           4.000e+01     
  19.000          90.000            1.023e+01          -5.092e+01             200.560           1.023e+01              41.498           4.000e+01     
  20.000          90.000            9.569e+00          -5.058e+01             187.424           9.569e+00              40.664           4.000e+01     
  21.000          90.000            8.897e+00          -4.999e+01             175.741           8.897e+00              39.896           4.000e+01     
  22.000          90.000            8.217e+00          -4.929e+01             165.969           8.217e+00              39.197           4.000e+01     
  23.000          90.000            7.537e+00          -4.859e+01             158.063           7.537e+00              38.561           4.000e+01     
  24.000          90.000            6.862e+00          -4.799e+01             151.775           6.861e+00              37.975           4.000e+01     
  25.000          90.000            6.198e+00          -4.751e+01             146.842           6.198e+00              37.415           4.000e+01     
  26.000          90.000            5.551e+00          -4.718e+01             143.075           5.551e+00              36.849           4.000e+01     
  27.000          90.000            4.927e+00          -4.701e+01             140.364           4.927e+00              36.234           4.000e+01     
  28.000          90.000            4.327e+00          -4.700e+01             138.697           4.327e+00              35.525           4.000e+01     
  29.000          90.000            3.754e+00          -4.715e+01             138.148           3.754e+00              34.669           4.000e+01     
  30.000          90.000            3.207e+00          -4.744e+01             138.886           3.207e+00              33.619           4.000e+01     
  31.000          90.000            2.682e+00          -4.784e+01             141.165           2.682e+00              32.332           4.000e+01     
  32.000          90.000            2.177e+00          -4.829e+01             145.285           2.177e+00              30.773           4.000e+01     
  33.000          90.000            1.685e+00          -4.868e+01             151.471           1.685e+00              28.919           4.000e+01     
  34.000          90.000            1.202e+00          -4.887e+01             159.571           1.202e+00              26.759           4.000e+01     
  35.000          90.000            7.217e-01          -4.872e+01             168.786           7.216e-01              24.298           4.000e+01     
  36.000          90.000            2.374e-01          -4.818e+01             177.798           2.373e-01              21.538           4.000e+01     
  37.000          90.000           -2.558e-01          -4.733e+01             185.411          -2.559e-01              18.503           4.000e+01     
  38.000          90.000           -7.627e-01          -4.632e+01             191.079          -7.628e-01              15.221           4.000e+01     
  39.000          90.000           -1.288e+00          -4.527e+01             194.839          -1.288e+00              11.722           4.000e+01     
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

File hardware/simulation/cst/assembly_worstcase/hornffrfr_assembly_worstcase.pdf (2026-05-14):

Components

1D Results\S-Parameters\S1,1

Farfields\farfield (f=1.42) [1]

Farfields\farfield (f=1.42) [1]

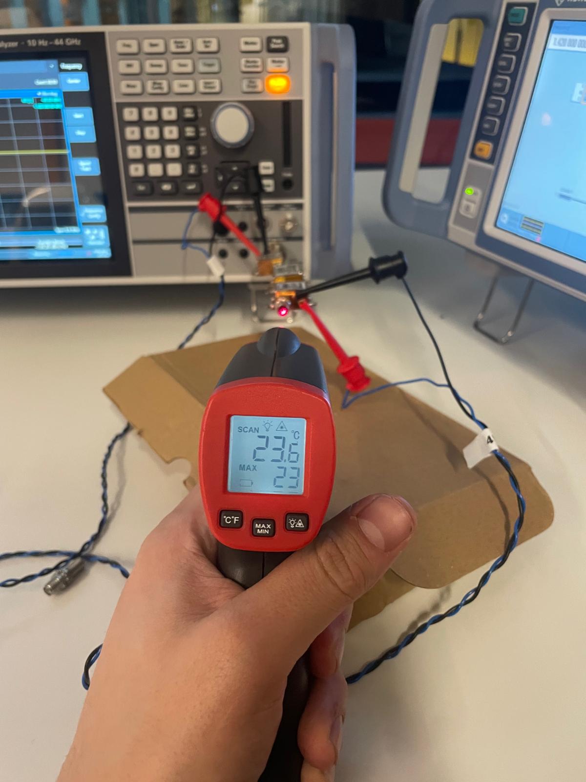
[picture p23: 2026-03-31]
measurements/rf-chain/nf/setup/WhatsApp Image 2026-03-29 at 01.58.57 (3).jpeg

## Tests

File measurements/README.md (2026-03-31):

# Measurements

Real-world measurements taken with calibrated test equipment, covering the RF chain components, full cascade, and the horn antenna.

## Equipment

| Item | Model |
|---|---|
| VNA | Rohde & Schwarz ZNB8 |
| Spectrum Analyzer | Rohde & Schwarz FSVA3044 |
| Calibration kit | ZV-Z270 |
| Calibration method | TOSM (full 2-port) |

## Contents

- [`rf-chain/`](rf-chain/) — All RF chain measurements, organized by type:
  - [`rf-chain/vna/`](rf-chain/vna/) — VNA-measured S-parameters using R&S ZNB8 (individual components + full cascade)
  - [`rf-chain/ip3/`](rf-chain/ip3/) — IP3 / intermodulation measurements (LNA, amp, cascade, cable-loss reference)
  - [`rf-chain/nf/`](rf-chain/nf/) — Noise figure measurements *(measured)*
- [`extras/`](extras/) — Test/debug components not in the final signal path (attenuators, 50 ohm matches)
- [`antenna/`](antenna/) — Horn antenna S11 measurements under various conditions, plus manufacturing defect documentation

## File Conventions

Each measurement folder contains:
- `.s2p` — Touchstone S-parameter data exported from the ZNB8
- `.pdf` — VNA screenshot/export showing S21 and S11 plots

## Viewing DAT Files

`.DAT` files in this folder are tab-delimited ASCII exports from the Rohde & Schwarz FSVA3044 spectrum analyzer. They can be opened with **[mergen-scope](https://alpgoxd.github.io/mergen-scope/)** ([GitHub](https://github.com/alpgoxd/mergen-scope)), an open-source R&S DAT file viewer.

## See Also

- [`hardware/rf-chain/datasheet-s-parameters/`](../hardware/rf-chain/datasheet-s-parameters/) — Manufacturer S-parameter files (Mini-Circuits)
- [`hardware/rf-chain/datasheets/`](../hardware/rf-chain/datasheets/) — Manufacturer PDF datasheets
- [`hardware/simulation/awr/`](../hardware/simulation/awr/) — AWR cascade simulation using datasheet data
- [`hardware/simulation/cst/`](../hardware/simulation/cst/) — CST antenna EM simulations

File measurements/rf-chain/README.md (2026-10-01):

# RF Chain Measurements

Lab characterisation of the three-stage RF receiver front-end (LNA → BPF → amplifier). All measurements were performed at room temperature with a Rohde & Schwarz ZNB8 VNA and FSVA3044 spectrum analyser.

## Cascade Summary

| Parameter | Value | Method |
|---|---|---|
| Gain (LNA + BPF + Amp) | 39.5 dB +/- 0.5 dB | VNA S21 (~42.5 MHz point spacing; no sample exactly at 1420.405 MHz, nearest points 1402.50835 MHz and 1445.0083 MHz) |
| Noise figure (cascade, cable-corrected) | about 1.5 dB (1.54 dB) | Gain-method output-noise measurement; see `nf/README.md` for the arithmetic |
| OIP3 (cascade) | +29.54 dBm | Two-tone, −12 dBm/tone input |

## Directory Structure

```
rf-chain/
├── vna/        VNA S-parameter measurements (.s2p + .pdf per component)
│   ├── ZX60-P162LN+/       LNA S-parameters
│   ├── ZX60-V63+/          Second amplifier S-parameters
│   ├── ZX75BP-1450-S+/     Bandpass filter S-parameters
│   └── cascade/            Cascaded chain S-parameters
├── nf/         Noise figure measurements (.DAT + .PNG, Rohde & Schwarz format)
└── ip3/        Intermodulation / OIP3 measurements
    ├── lna/        LNA alone
    ├── amplifier/  ZX60-V63+ alone
    └── cascade/    Full chain
```

## VNA Measurements (`vna/`)

Each component has:
- `.s2p` — Touchstone S-parameter file (S11, S21, S12, S22 vs frequency)
- `.pdf` — VNA plot exported from the ZNB8

The `cascade/` subdirectory contains `cascaded chain.s2p`, the end-to-end S21 of the full chain (horn N-type connector to PlutoSDR SMA input).

The single-stage files are not de-embedded; the filter file includes test adapters and cables, which is why the stages sum to 37.8 dB against the 39.5 dB cascade. The cascade file is the reference for the chain gain. `software/analysis/stage_gains.py` computes all stage gains at 1420.405 MHz.

Compare with datasheet S-parameters in `hardware/rf-chain/datasheet-s-parameters/`.

## Noise Figure Measurements (`nf/`)

Measured with the R&S FSVA3044 using the gain method: the output noise density of the chain with its input terminated in 50 Ω, minus the known chain gain (not a Y-factor measurement). Files:
- `cable_loss.DAT` / `.PNG` — Cable insertion loss at 100 kHz steps (used for loss correction)
- `just cooked reciver.DAT` / `.PNG` — First NF measurement of the assembled receiver
- `match noise.DAT` — Repeated measurement after connector reseating (more consistent)
- `match noise again.PNG` — Overlay confirming repeatability

Setup photos are in `nf/setup/`.

## IP3 / Intermodulation Measurements (`ip3/`)

Two-tone IP3 test at three input power levels (−12, −15, −18 dBm per tone) for:
- LNA alone
- Second amplifier alone
- Full cascade

Each set contains `.DAT` (spectrum analyser trace data) and `.PNG` plots. Setup photos (VSG settings, bench layout) are in `ip3/setup/`.

See `hardware/rf-chain/COMPONENTS.md` for the component cross-reference linking these measurements to datasheet S-parameters and AWR simulations.

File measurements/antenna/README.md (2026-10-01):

# Antenna Measurements

S11 measurements of the horn antenna under different conditions, listed in chronological order. Each step builds on the previous one. All measurements use the R&S ZNB8.

## Measurement Log (Chronological Order)

| # | Folder | Calibrated | Location | Notes |
|---|---|---|---|---|
| 1 | `1_outside_uncalibrated/` | No | Outdoor | First quick test — VNA was not calibrated |
| 2 | `2_outside_calibrated/` | Yes (TOSM) | Outdoor | Calibrated VNA with cal kit, re-measured outdoors |
| 3 | `3_inside_calibrated/` | Yes (TOSM) | Indoor | Brought antenna inside, measured again (same cal) |
| 4 | `4_inside_aluminum_foil/` | Yes (TOSM) | Indoor | Aluminum foil added at E/H-plane merge point to test sealing (photo included) |
| 5 | `5_inside_cleaned_backshort/` | Yes (TOSM) | Indoor | **FINAL** — Cleaned interior with wipes; backshort pin removed and re-inserted. Better than −30 dB from 1410 to 1440 MHz; −41.8 dB at the 1420.000 MHz sample (10 MHz grid, so the null depth is not resolved) |

> **Note:** Measurement #5 is the **definitive measurement** representing the antenna as-built.

## Known Manufacturing Defect

The aluminum sheet used for the horn was obtained for free because it was bent by the manufacturer. As a result, the horn walls are **concave in** (bowed inward along the length of the antenna). See [`antenna_photos/`](antenna_photos/) for photo documentation.

This concavity may affect:
- Aperture efficiency (non-planar phase front)
- Gain reduction compared to the ideal horn simulation
- Slight pattern asymmetry

Compare with simulations:
- [`simulation/cst/ideal_horn/`](../../hardware/simulation/cst/ideal_horn/) — Ideal geometry
- [`simulation/cst/assembly_worstcase/`](../../hardware/simulation/cst/assembly_worstcase/) — Worst-case assembly model

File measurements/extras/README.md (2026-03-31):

# RF Chain Extras — Test Components

VNA measurements of components used during testing and verification. **These are not part of the final RF signal path.**

## Contents

- `attenuators/` — Attenuator S-parameter measurements
- `50ohm-match/` — 50 ohm termination / match measurements

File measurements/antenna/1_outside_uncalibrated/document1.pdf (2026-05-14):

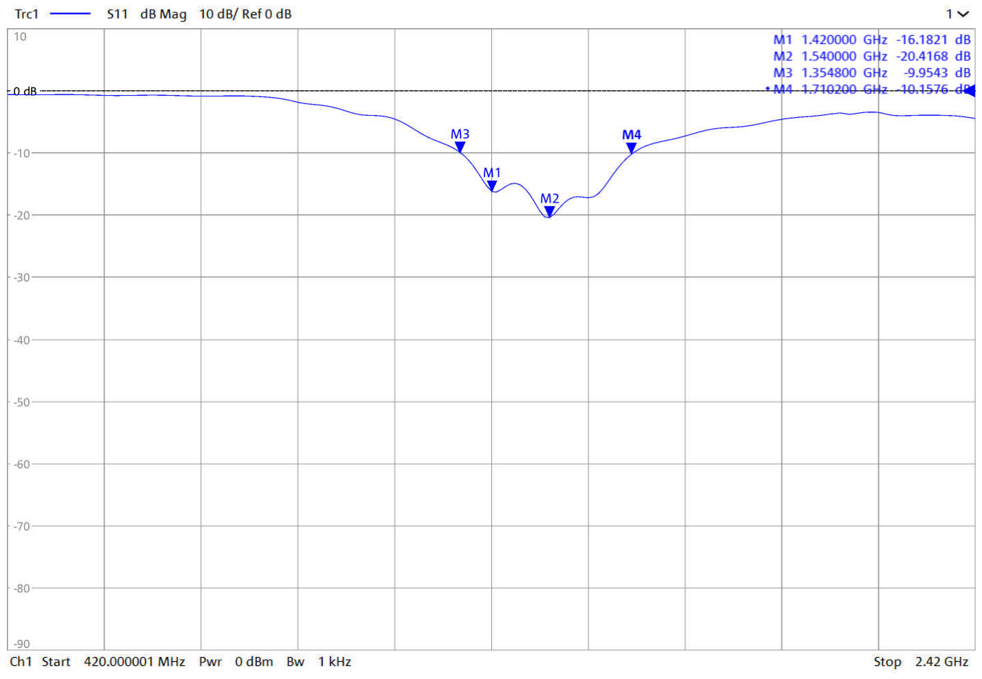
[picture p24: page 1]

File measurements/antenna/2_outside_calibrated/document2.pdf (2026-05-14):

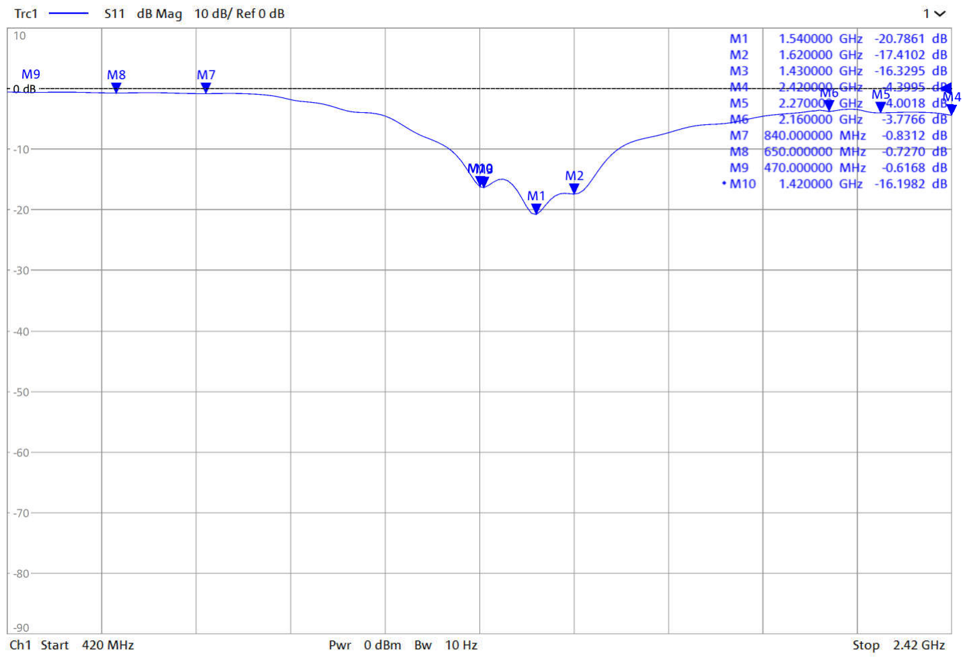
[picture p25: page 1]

M4

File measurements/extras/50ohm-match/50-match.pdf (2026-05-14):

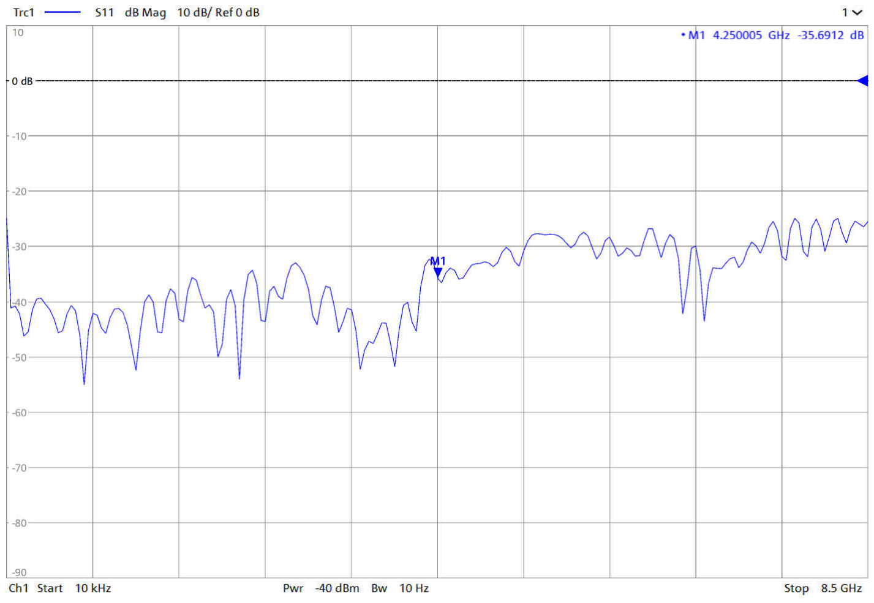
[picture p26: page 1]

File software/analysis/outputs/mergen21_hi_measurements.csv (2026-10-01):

id | kind | source_file | utc_mid | n_rows | on_source_s | az_deg | alt_deg | tau_row_s | ra_deg | dec_deg | l_deg | b_deg | centroid_kHz | centroid_err_kHz | centroid_moment_kHz | amp_pct | amp_err_pct | smoothed_peak_pct | raw_peak_excess_pct | fwhm_kHz | fwhm_err_kHz | fwhm_kms | halfpower_width_kHz | v_bary_kms | v_solar_kms | v_motion_kms | v_lsr_kms | v_lsr_moment_kms | rms_frac | rms_diff_frac | rms_row_frac | dT_baseline_K | dT_diff_K | rms_expected_from_rows | rms_ratio_meas_over_expected | snr_peak
W | static | mergen21_spec_20260429_045525_bati.dat | 2026-04-29T01:56:18.000 | 106 | 106.0 | 270.0 | 30.0 | 1.0 | 208.347 | 19.281 | 7.31 | 73.77 | 77.76 | 2.78 | 98.31 | 5.447 | 0.345 | 4.507 | 5.475 | 151.87 | 7.94 | 32.05 | 93.0 | -8.723 | 10.474 | 1.751 | -14.66 | -19.0 | 0.004146 | 0.003349 | 0.037923 | 0.802 | 0.648 | 0.003683 | 0.909 | 16.3
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

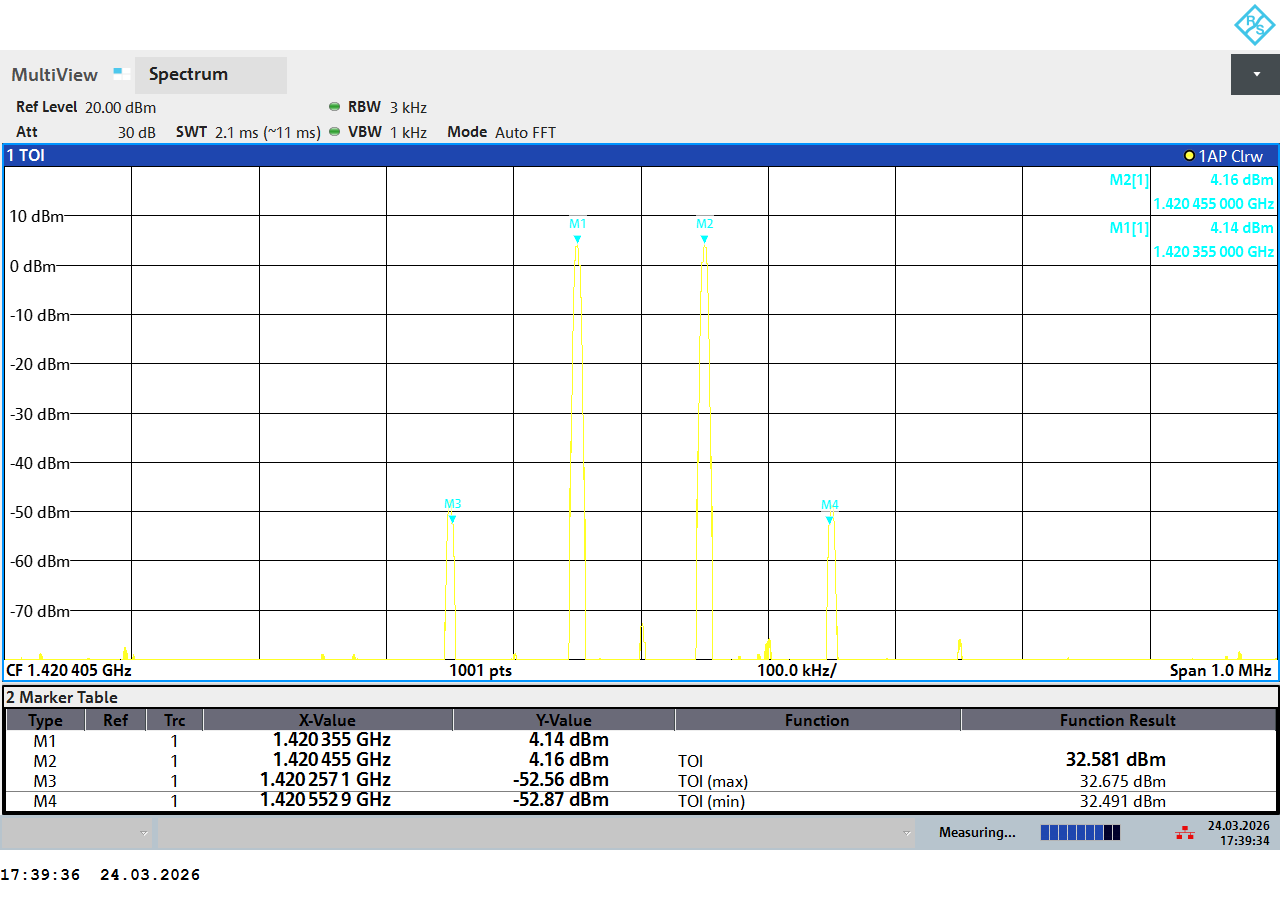
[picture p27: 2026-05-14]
measurements/rf-chain/ip3/cascade/cascade_ip3_-15dBm.PNG

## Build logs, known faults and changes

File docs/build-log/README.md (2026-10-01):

# Build Log

Chronological construction notes, issues, and solutions.

## 2026-04-29

- First-light observations completed. The horn rested on its narrow (80 mm) wall with the N-connector axis horizontal (E-plane horizontal), not hand-held; the 3D-printed tripod mount was not used (see note in hardware/antenna/3d-print/).

## 2026-03-30

- Moved build photos into this folder.
- Added top-level documentation cleanup pass and status tracking.

### Photos in this folder

- `aluminum-cutting.jpeg`
- `bent-aluminum.jpeg`
- `near_assembly_horn.jpeg`
- `nextto_banana.jpeg`
- `antenna_mounted.jpeg` — antenna set up for first-light session

## 2026-03-29

- Antenna assembly documentation significantly expanded in [`../../hardware/antenna/ASSEMBLY.md`](../../hardware/antenna/ASSEMBLY.md).
- Added detailed assembly sequence, lessons learned, and full photo-backed notes.

## Notes

- The fuller assembly narrative lives in [`../../hardware/antenna/ASSEMBLY.md`](../../hardware/antenna/ASSEMBLY.md).
- This file is the short chronological index.

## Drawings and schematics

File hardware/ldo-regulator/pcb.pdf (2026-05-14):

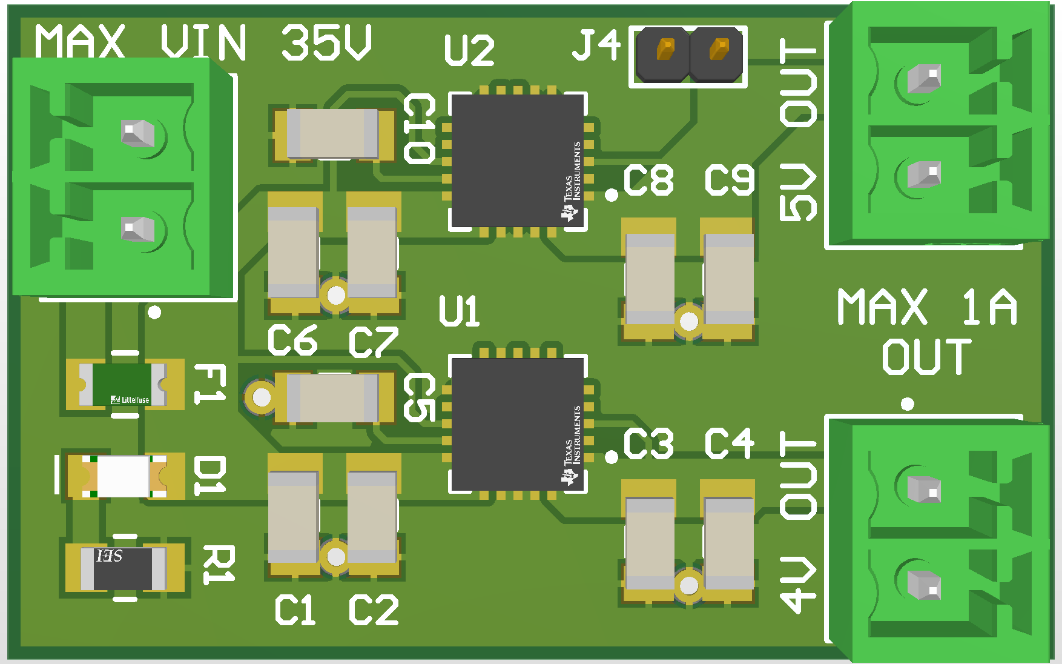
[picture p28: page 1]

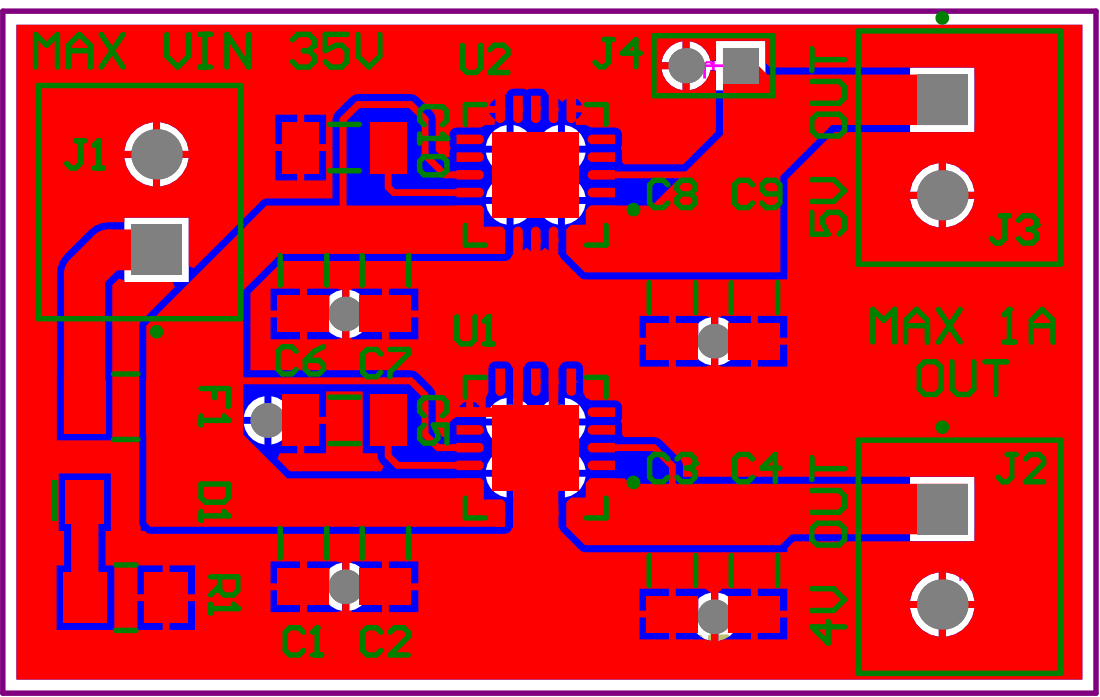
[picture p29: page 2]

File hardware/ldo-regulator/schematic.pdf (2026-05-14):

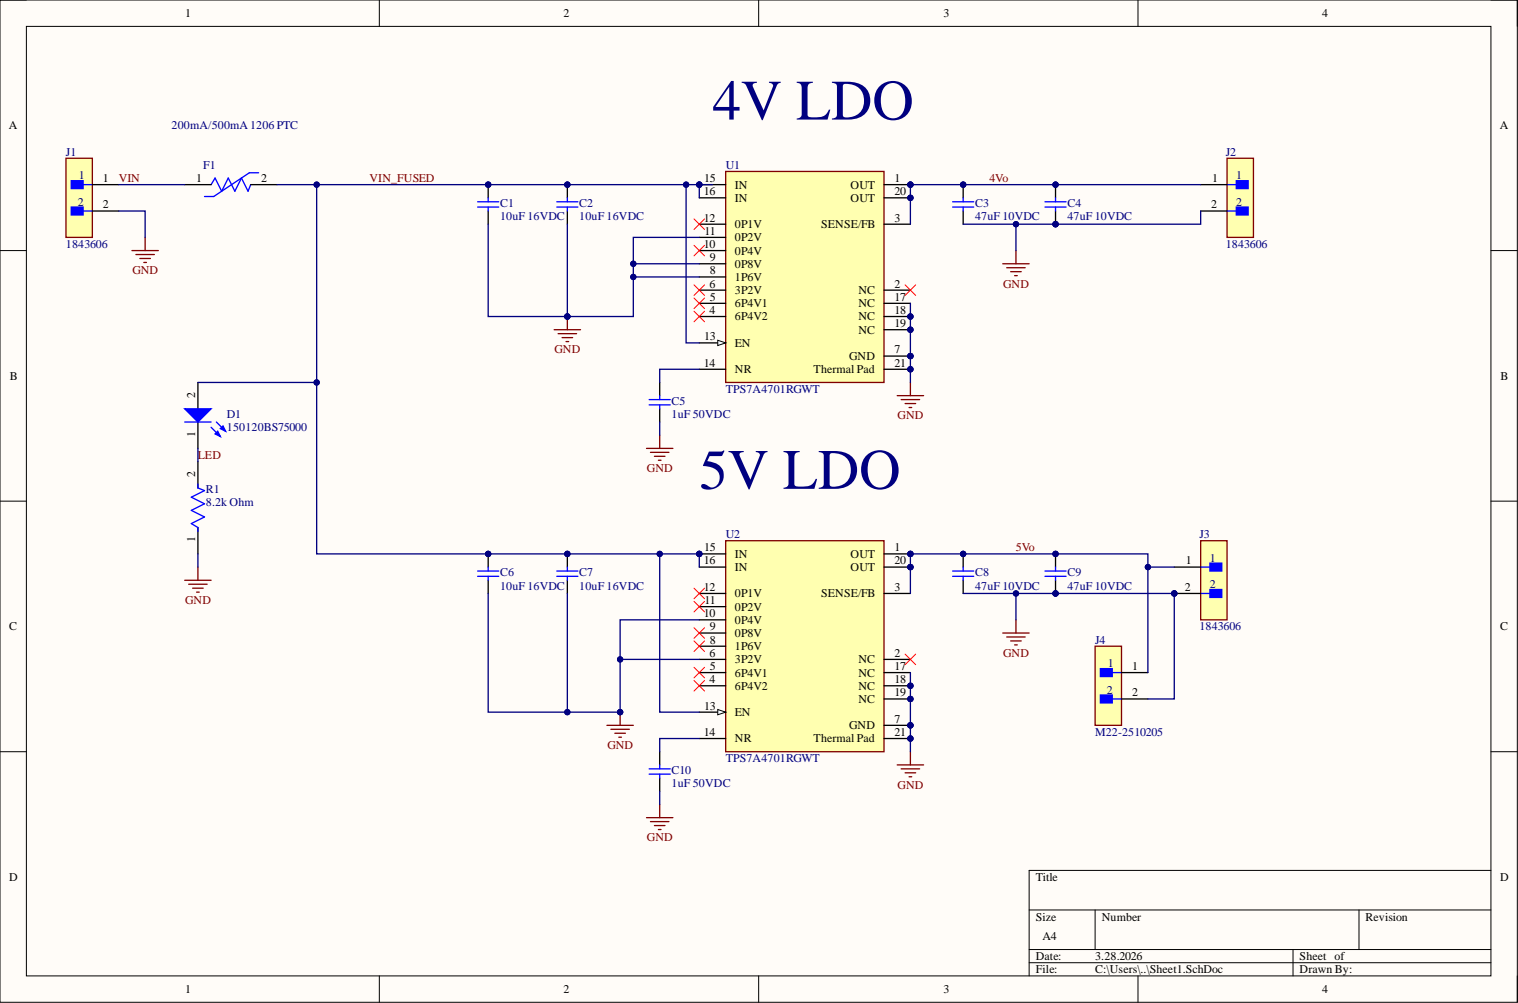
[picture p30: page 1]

4 | 1 8
1 3 | 1 9

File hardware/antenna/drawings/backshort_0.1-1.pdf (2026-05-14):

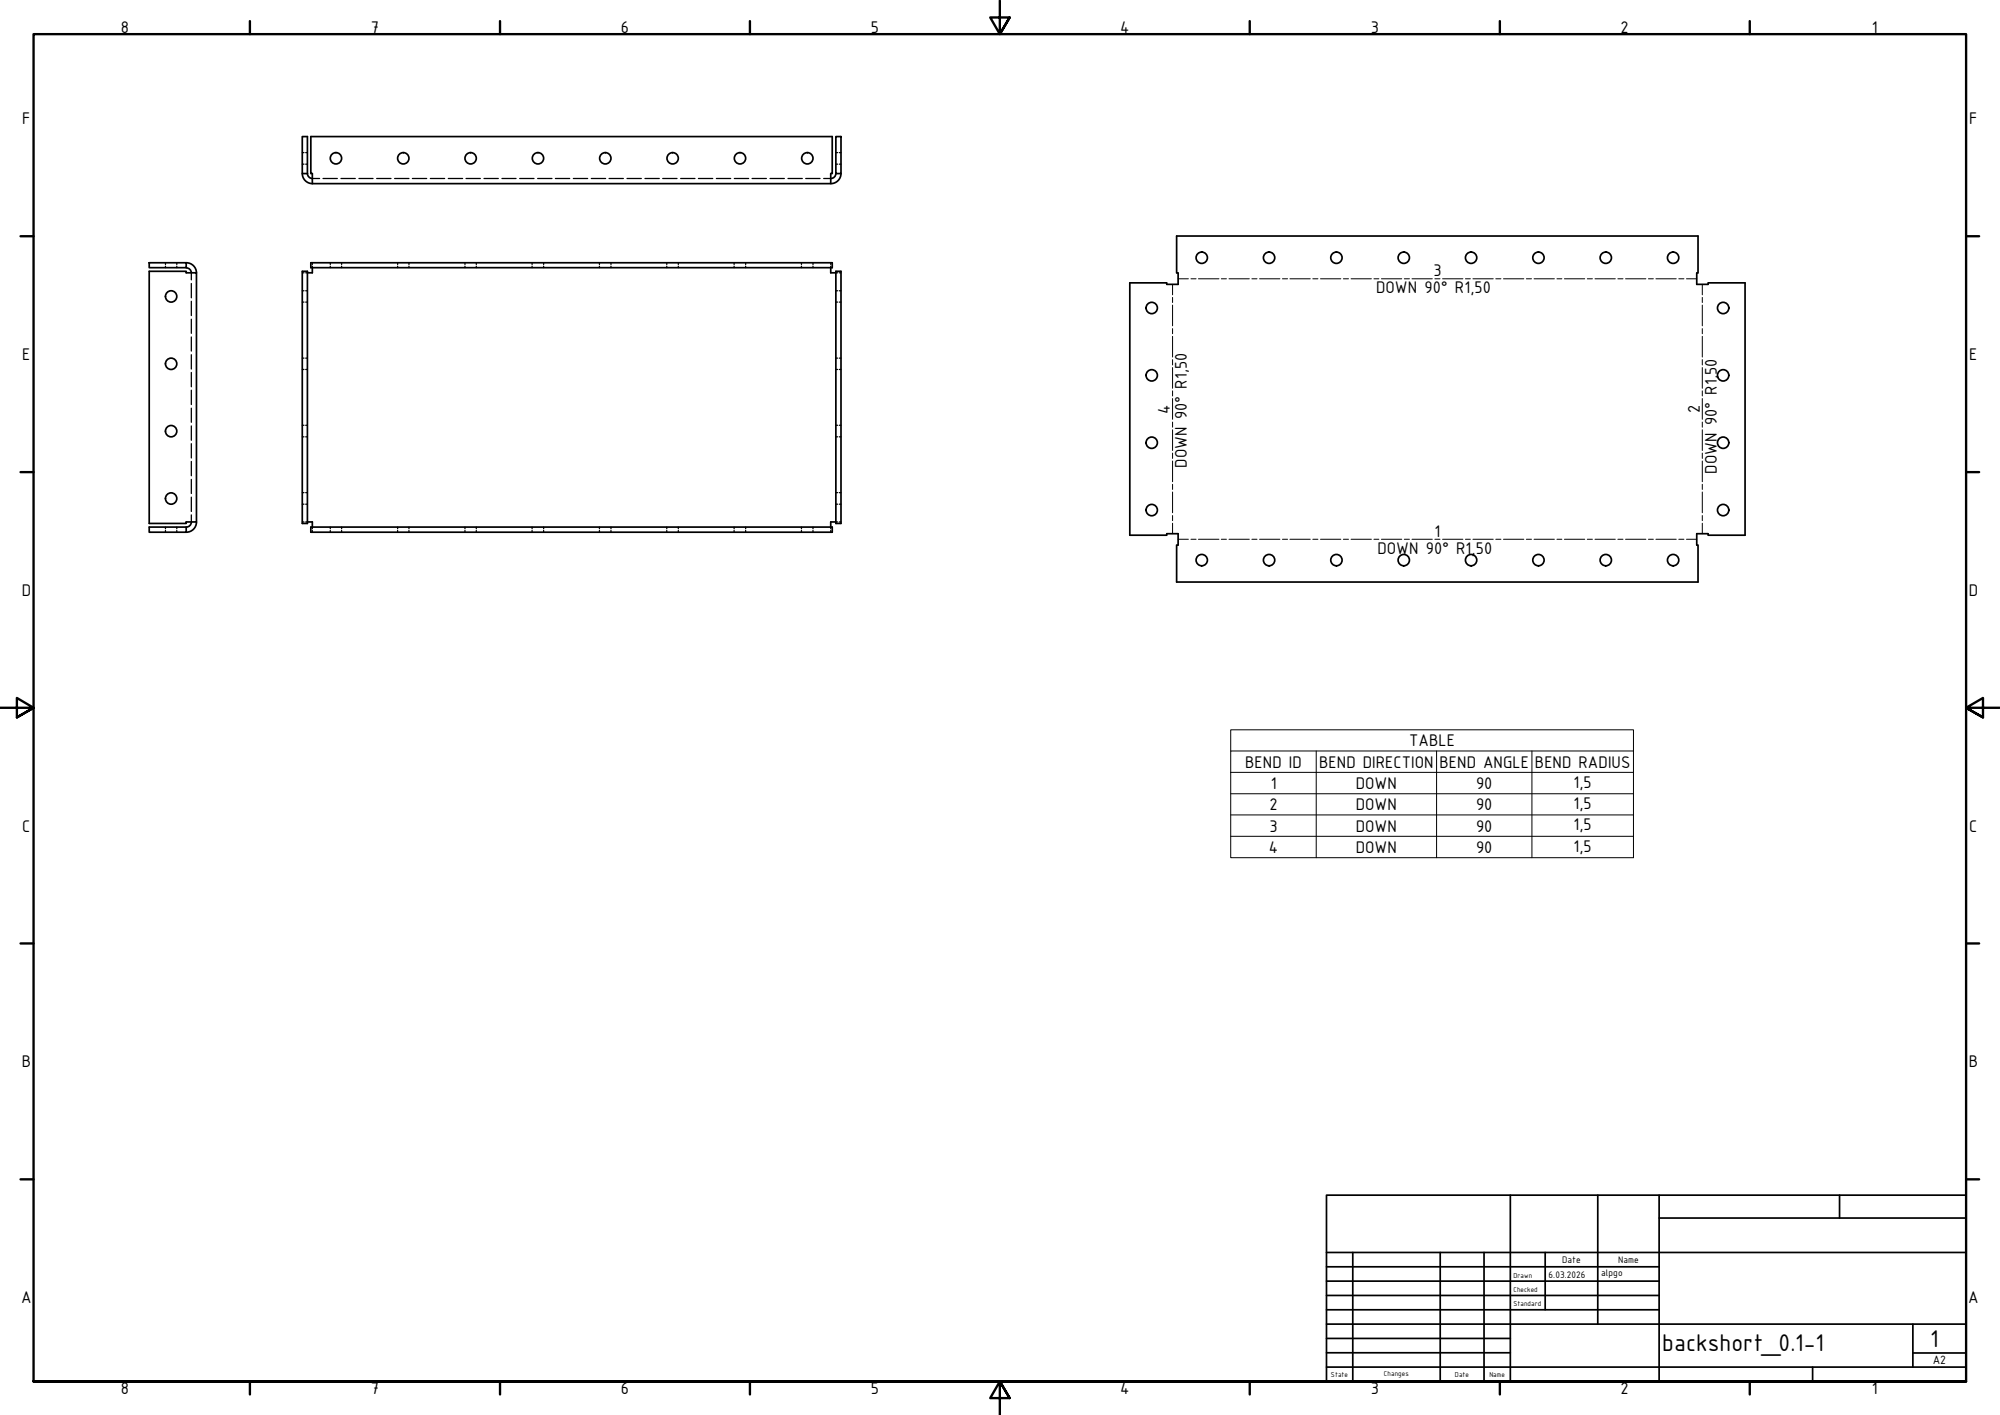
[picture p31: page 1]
DOWN 90° R1,50

BEND ID | BEND DIRECTION | BEND ANGLE | BEND RADIUS
1 | DOWN | 90 | 1,5
2 | DOWN | 90 | 1,5
3 | DOWN | 90 | 1,5
4 | DOWN | 90 | 1,5

Date | Name

Drawn | 6.03.2026 | alpgo

Checked

Standard

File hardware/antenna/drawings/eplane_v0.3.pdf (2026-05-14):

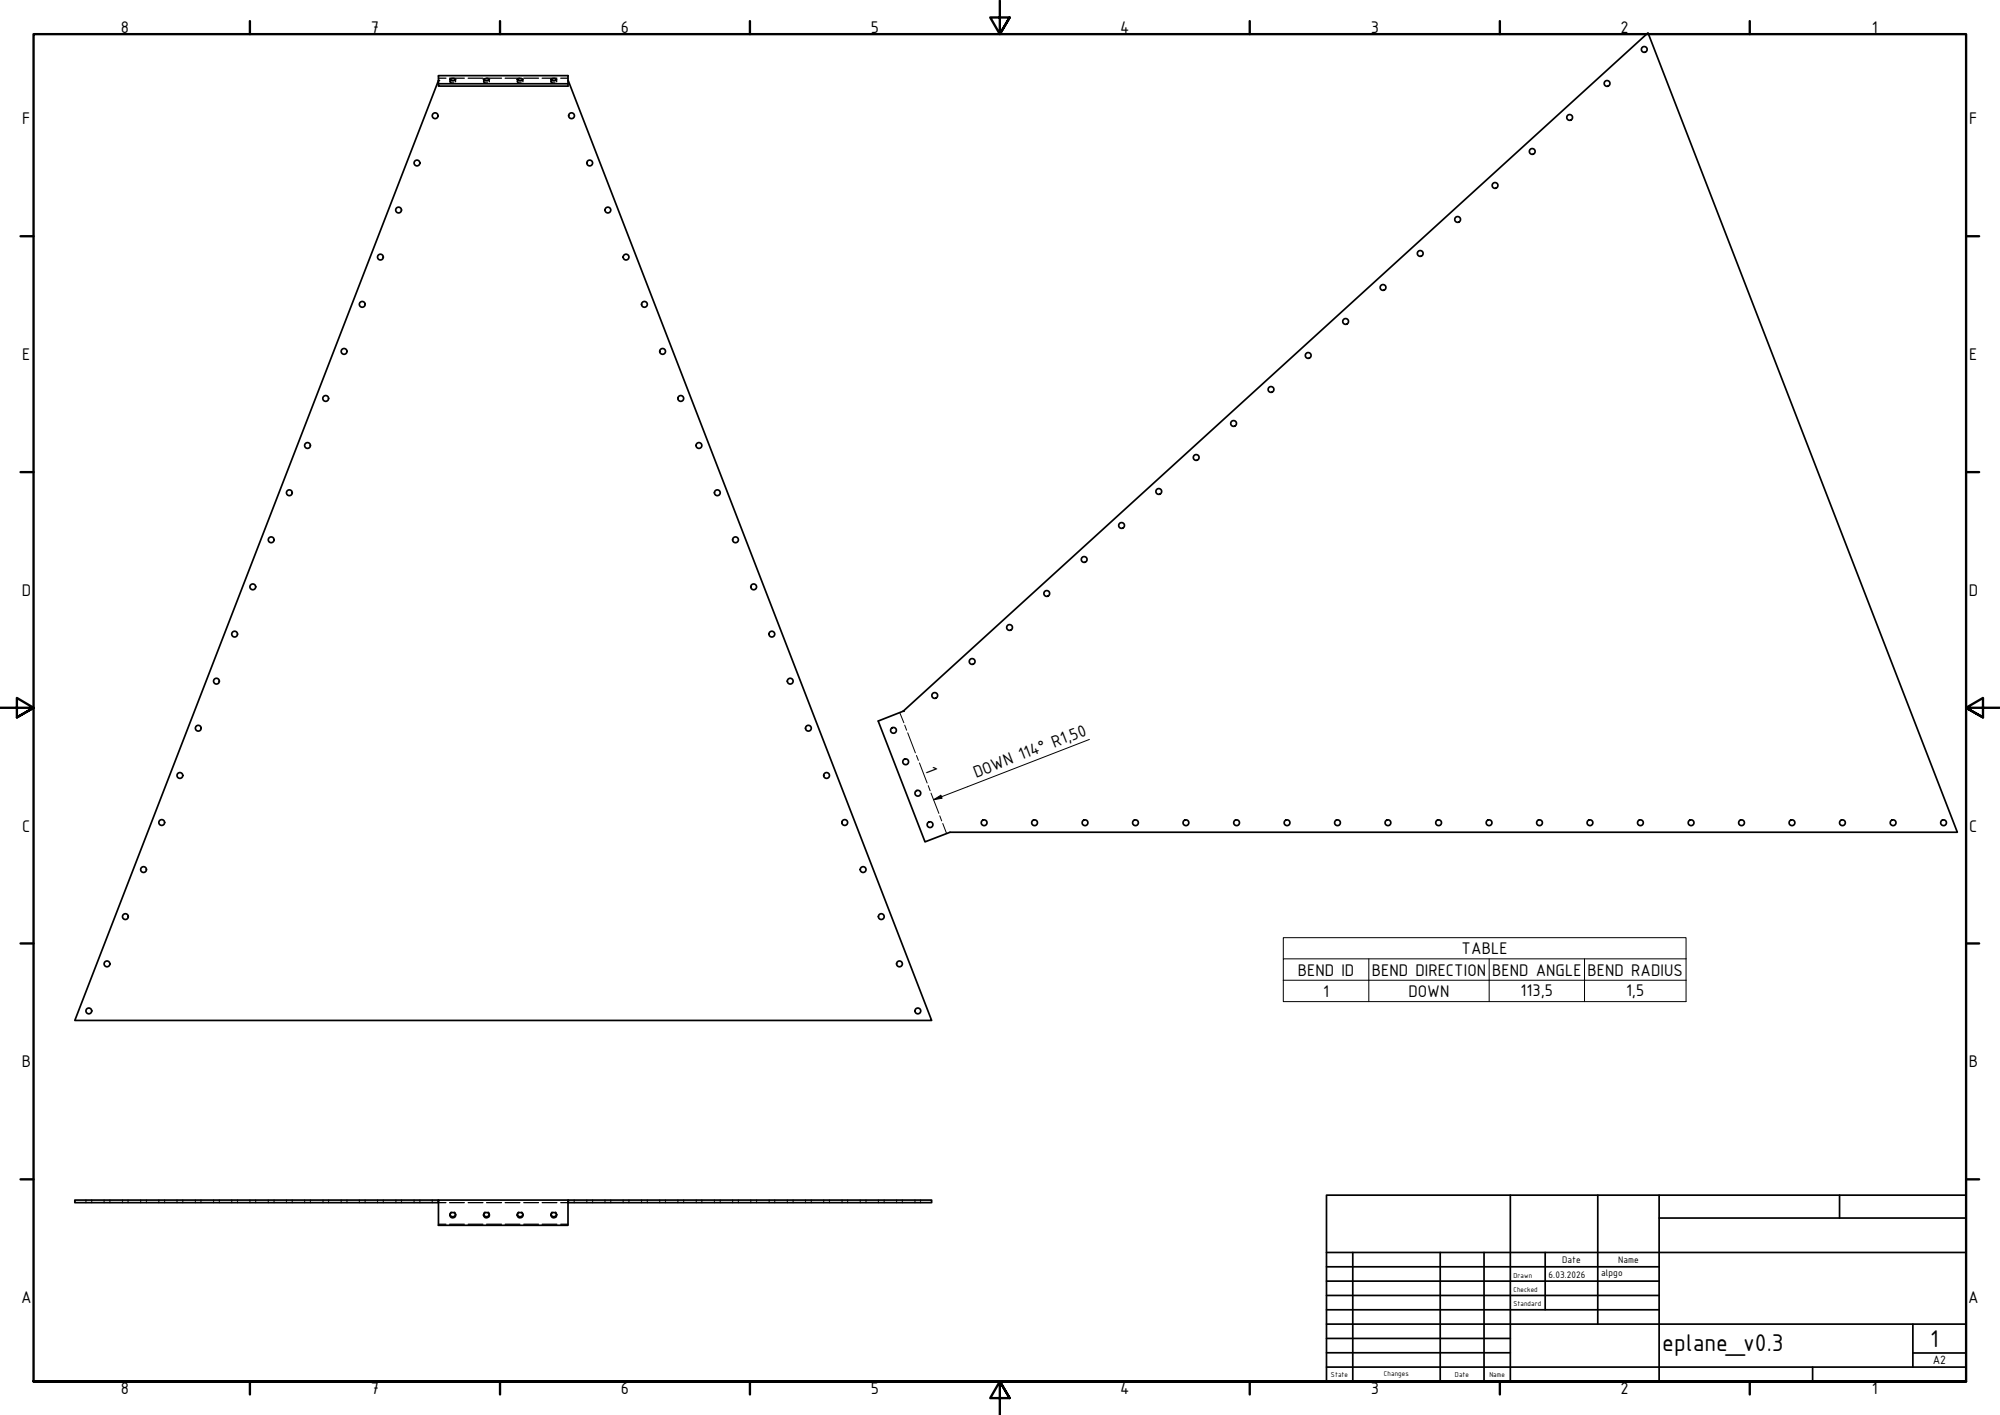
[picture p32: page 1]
DOWN 114° R1,50

BEND ID | BEND DIRECTION | BEND ANGLE | BEND RADIUS
1 | DOWN | 113,5 | 1,5

Date | Name

Drawn | 6.03.2026 | alpgo

Checked

Standard

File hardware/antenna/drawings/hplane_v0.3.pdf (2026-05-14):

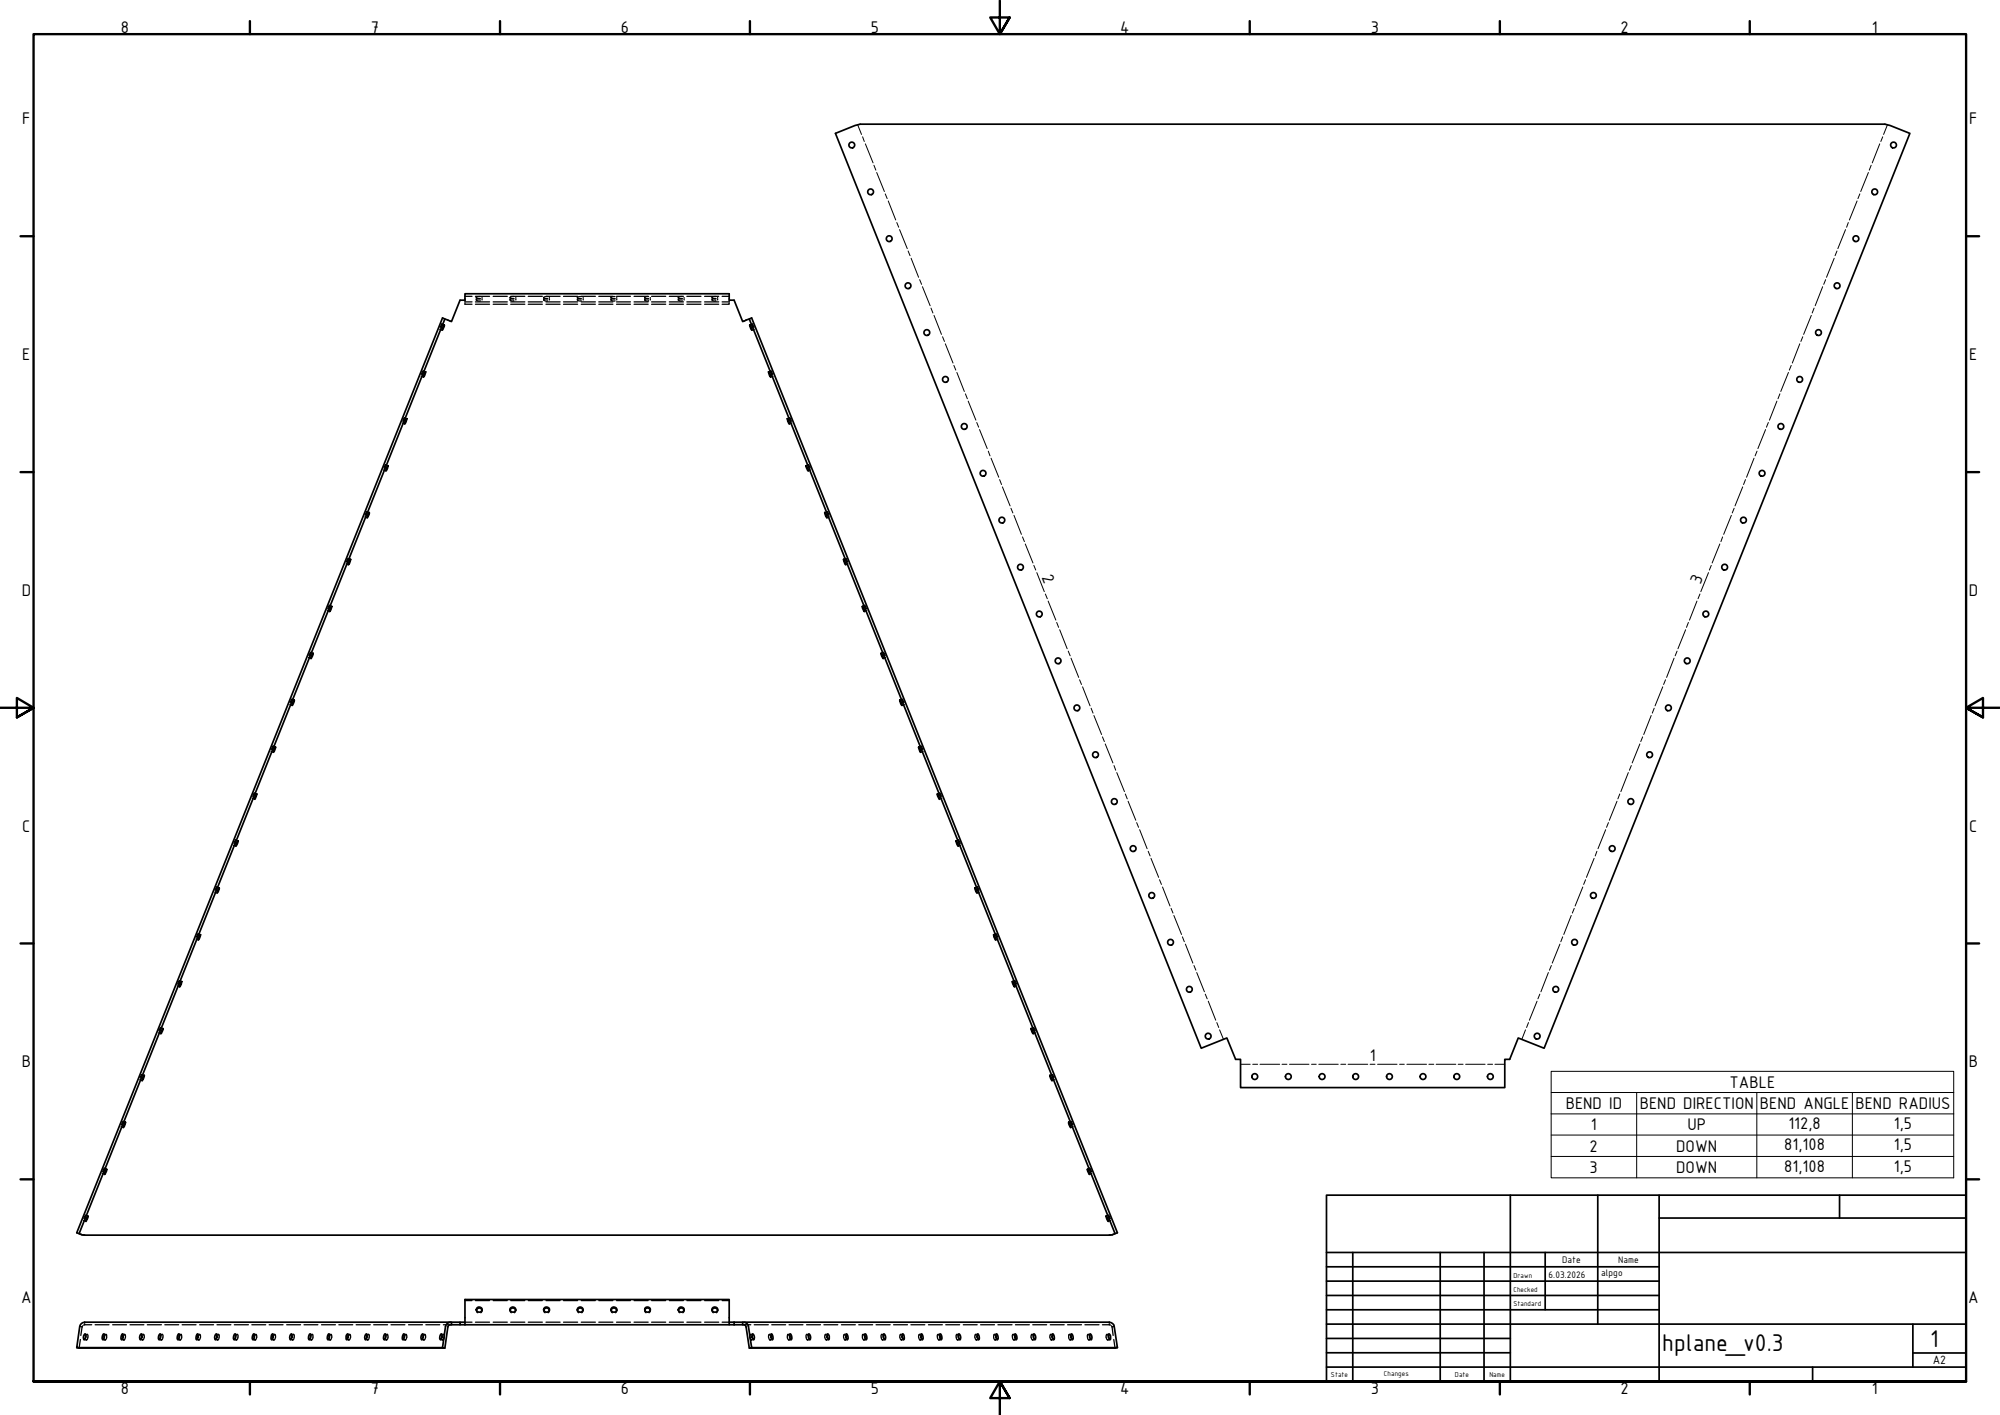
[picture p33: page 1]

BEND ID | BEND DIRECTION | BEND ANGLE | BEND RADIUS
1 | UP | 112,8 | 1,5
2 | DOWN | 81,108 | 1,5
3 | DOWN | 81,108 | 1,5

Date | Name

Drawn | 6.03.2026 | alpgo

Checked

Standard

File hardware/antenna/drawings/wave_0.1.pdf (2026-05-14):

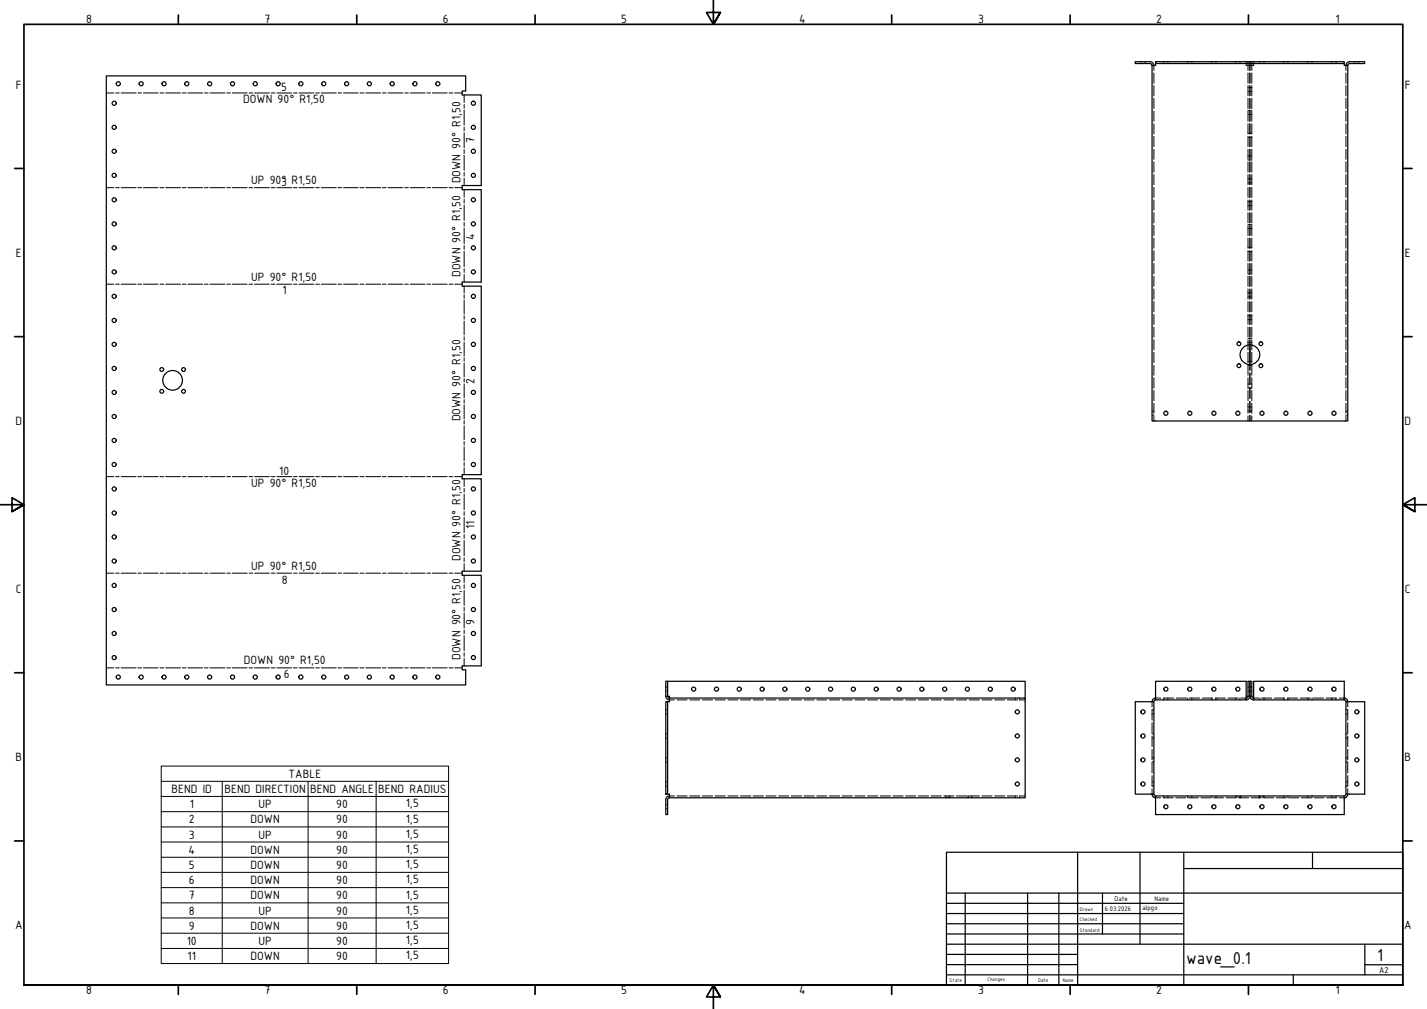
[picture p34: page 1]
DOWN 90° R1,50

B E N D ID | B E N D DIR E C TIO N | B E N D A N G L E | B E N D R A DIU S
1 | U P | 9 0 | 1,5
2 | D O W N | 9 0 | 1,5
3 | U P | 9 0 | 1,5
4 | D O W N | 9 0 | 1,5
5 | D O W N | 9 0 | 1,5
6 | D O W N | 9 0 | 1,5
7 | D O W N | 9 0 | 1,5

9 | D O W N | 9 0 | 1,5
1 0 | U P | 9 0 | 1,5
1 1 | D O W N | 9 0 | 1,5

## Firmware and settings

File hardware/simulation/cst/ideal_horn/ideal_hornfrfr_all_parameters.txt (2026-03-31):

wave_a="160" "waveguide width"
wave_b="80" "waveguide height"
wave_l="215+qtr_wavelenght" "waveguide lenght"
horn_w="608" "horn width"
horn_h="513" "horn_h"
horn_l="515" "hon_l"
mt="1.5" "sheet metal thikness"
backshot="qtr_wavelenght-backshot_offset" ""
f_center="1.42" ""
wavelenght="clight/(f_center*10^9)" ""
cutoff_lower="clight/(2*wave_a/1000)" ""
cutoff_lower_ghz="cutoff_lower/10^9" ""
cutoff_lower_wavelenght="clight/cutoff_lower" ""
k="(wavelenght/cutoff_lower_wavelenght)^2" ""
p="sqr(1-k)" ""
waveguide_wavelenght="wavelenght/p*1000" ""
half_wavelenght="waveguide_wavelenght/2" ""
qtr_wavelenght="waveguide_wavelenght/4" ""
backshot_offset="29" ""
pin_diameter="3" ""
interface_height="20.8" ""
Dielectric_Diameter="10.03" "dielectric diameter"
outer_diameter="16" ""
pin_depth="38" "waveguide coax pin depth"
total_m2="2*((horn_w+wave_a)/2*sqr(horn_l^2+((horn_w-wave_a)/2)^2)+(horn_h+wave_b)/2*sqr(horn_l^2+((horn_h-wave_b)/2)^2))*1e-6" ""
connin="2.8" ""
conn_met="7" ""

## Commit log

2026-04-09 added gnu radio flowgraphs for both reciver and a synth
    Add multiple GNU Radio Companion flowgraphs and their generated Python scripts for 21cm experiments: fftdemo (simple FFT demo), testingit (Pluto RX/TX with FFT, integration and vector sinks), topo1_c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
2026-04-17 Add tripod CAD and update GNURadio flows
    Add new tripod CAD/3D-print files (3mf, ipt) and update existing Inventor/STL assets; remove obsolete assembly (.iam). Update multiple GNURadio topologies and scripts: adjust GUI block coordinates, add/attach qtgui sinks (replace some fft/integration plumbing in topo3 with qtgui.sink_c), move a qtgui_freq_sink connection in topo1, and enable writing integrated data to a new file sink. Update receiver defaults: change Pluto URI to 192.168.10.1, set LO to 1420405000, reduce integration_time to 50, add file sink for calibration outputs, and remove unused TX sink/controls. Also add binary calibration files (calibaartion20/30/40). These changes tidy the UI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
    [tripode_mount.3mf, tripode_mount.iam, tripode_mount.ipt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]
2026-05-12 Add first-light data, viewer, and docs updates
    Publish first-light observations and supporting software/docs: add many 2026-04-29 raw spectra (.dat) and directional sweep plots (PNG); introduce interactive waterfall viewer (software/analysis/merg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
2026-05-14 Docs: README and build-log updates + plots
    Revise README for clarity and project status, add images and diagrams (antenna mount, GNU Radio flowgraph), and document first-light observations (2026-04-29). Update build-log with first-light note 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
2026-09-23 [docs] Carry forward pending README and flowgraph edits onto paper-release
    Pre-existing uncommitted working-tree edits from before this branch:
    docs quickstart/navigation improvements in README.md and
    observations/README.md, .gitignore additions (LaTeX artifacts,
    software/gnuradio/logs/), and reciver.grc/.py settings changes
    (integration_time 500->1000, rx_gain 30->0, log_dir made relative).
2026-09-23 Add HI analysis and averaging scripts from analysis workspace
    Bring in mergen21_hi_analysis.py, first_light_and_averaging.py, and
    wola_window_check.py from the analysis workspace, plus the S11/far-field
    figure scripts, TikZ figure sources, reference outputs, and provenance
    docs, per REPO_FIX_PROMPT.md tasks 1-2.
    [averaging_noise.csv, mergen21_capture_metadata.csv, mergen21_data_manifest.csv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]
2026-09-23 Add observations/captures.csv with acquisition provenance
    Derived from the observer-confirmed capture metadata, with added
    date and start_utc (local - 3h) columns.
    [captures.csv]
2026-09-23 gnuradio README: document disabled injector and WOLA truncation known issue
    Note that the simulated HI-line TX injector chain is saved
    disabled and uses a separate PlutoSDR URI from RX, without
    claiming anything about the April 29 captures (left as a TODO).
    Document the WOLA prototype filter truncation (32,299 designed
    taps vs 16,384 used) and point to wola_window_check.py.
2026-09-23 Fix doubled .s1p extension on antenna measurement file
    alp_anten_lab_0_enhanced.s1p.s1p had a doubled extension typo.
    Renamed with git mv to alp_anten_lab_0_enhanced.s1p; blob content
    verified byte-identical (sha256 2837a962...872097d7 before and
    after). Updated the one reference to the old name in
    docs/lab-manual-03-measure.md.
2026-09-23 Add MISSING_FROM_RELEASE.md audit
    Reports presence/absence of items the paper references but that may
    not be in the repository: the 50 ohm-terminated SDR capture (absent;
    distinct from the matched-load VNA S11 measurement, which is present),
    the receiver-connected-vs-SDR-terminated comparison behind the claimed
    0.056 dB SDR noise figure (absent, whole-repo search), the two
    cable-loss files under nf/ and ip3/cable-loss/ (both present, distinct
    files), the antenna probe-trimming milestone sequence (exactly 5,
    no finer intermediate cuts found), CST project files (none found;
    .gitignore already excludes *.cst/*.awr), and far-field/TikZ figure
    sources (raw .txt cuts present under hardware/simulat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
2026-09-23 Correct sweep row cadence comment (TAU_ROW_SWEEP_S) to 1.0 s
    The observer confirmed on 2026-09-13 that the sweep capture
    (_180partygirl_500int.dat) ran with integration_time = 1000 (1.0 s/row)
    despite its filename's misleading "500int". Verified before/after that
    this only changes the withdrawn sweep-block on_source_s/utc_mid/tau_row_s
    columns and frequency_axis.tau_per_row_s_sweep in the derived JSON; the
    three static-pointing summary (mergen21_hi_line_parameters.csv), the
    noise-figure arithmetic, and the data manifest are byte-identical.
    Also updates stale comments referencing the flowgraph's integration_time
    value now that software/gnuradio/reciver.grc's default has been corrected.
    Co-A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
2026-09-23 Pin software/requirements.txt
    Pin numpy, scipy, pandas, matplotlib, and astropy to the versions
    installed and verified to run the analysis scripts (Python 3.14.3).
2026-09-23 Add regenerated analysis outputs and VERIFICATION.md
    Run mergen21_hi_analysis.py and first_light_and_averaging.py against this
    checkout (offline, IERS auto-download disabled) and commit the regenerated
    CSVs, JSON, and figures under software/analysis/outputs/, plus
    VERIFICATION.md comparing every value against software/analysis/reference_outputs/.
    All fitted line parameters (amplitude, centroid, FWHM), the averaging-noise
    table, the line-free channel count, and the cable-corrected noise figure
    (1.54 dB) reproduce exactly. Galactic l/b and derived velocities differ by
    up to 0.1 deg/km/s, consistent with the offline-IERS caveat. The WOLA
    prototype-filter check remains blocked in this environme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
    [averaging_noise.csv, mergen21_data_manifest.csv, mergen21_hi_line_parameters.csv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]
2026-09-23 Correct NF/gain claims in README and reword rotation curve as future work
    Cascade NF is a cable-corrected ~1.5 dB gain-method estimate, not 0.75 dB.
    Cascade gain is 39.5 dB +/- 0.5 dB; the VNA cascade file has no sample at
    1420.405 MHz. The rotation curve is a future goal, not a completed result.
    Also adds a "Reproducing the paper" section pointing at the actual
    analysis scripts and their verification/provenance docs.
2026-09-23 Rewrite NF section arithmetic to cable-corrected ~1.5 dB
    Show the corrected noise-figure equation legibly (device-plane, cable-
    corrected: -133.46 + 0.6 - (-173.9) - 39.5 = 1.54 dB), state the Friis
    prediction (0.77 dB) and design requirement (0.96 dB) explicitly, and
    remove the false "0.02 dB agreement" / "cable loss neglected" claims.
    Only the interpretation and arithmetic change; the raw measurement
    description is unchanged.
2026-09-23 Correct cascade gain/NF summary table
    39.5 dB +/- 0.5 dB gain (VNA has no sample at 1420.405 MHz) and
    ~1.5 dB cable-corrected NF, matching nf/README.md.
2026-09-23 Correct CLAUDE.md gain/NF numbers and analysis-pipeline status
    Matches the corrected 39.5 dB / ~1.5 dB measurements and reflects that
    mergen21_hi_analysis.py and first_light_and_averaging.py now exist and
    do real analysis; K/Jy calibration and rotation-curve extraction remain
    future work.
2026-09-23 Correct gain/NF numbers in lab manuals; flag rotation curve as future work
    Labs 1 and 3: cascade gain 39.5 dB +/- 0.5 dB (VNA has no sample at
    1420.405 MHz) and cable-corrected NF ~1.5 dB, replacing 39.7/0.75.
    Lab 4: Part C (tangent-point rotation curve) is labeled a future
    exercise, not something performed on the released dataset.
2026-09-23 Update analysis README to describe the actual scripts, not a planned pipeline
    mergen21_hi_analysis.py and first_light_and_averaging.py now exist and do
    real line fits and averaging-noise analysis; the old "Planned Pipeline"
    was stale. Also corrects the 39.7/0.75 dB calibration-reference numbers
    and flags rotation-curve extraction as future work.
2026-09-23 Fix stale NF number in gnuradio README
    0.75 dB -> ~1.5 dB (cable-corrected), matching measurements/rf-chain/nf.
    No other change to this file.
2026-09-23 [software] Restore rx_gain = 30 to match the 2026-04-29 captures
    The released flowgraph should describe how the released data was
    taken. reciver.py was synced by hand (grcc is not available here).
2026-09-23 [docs] Add docs index, BOM, build lab manual, and hardware READMEs
    README.md already links to docs/bom.md and the lab manuals; these
    files were present locally but never committed.
2026-09-23 [docs] Update PR description with resolved decisions
    Data license, rx_gain, and the untracked docs are resolved; remaining
    open items are renumbered. Footer switched to the PR attribution line.
2026-09-23 [docs] Final cleanup before merging to main
    Fix a broken relative link in hardware/antenna/README.md and drop
    PR_DESCRIPTION.md (no PR is being opened; the changes merge straight
    into main). Its open items remain in the commit history.
2026-10-01 [task 4] Correct E/H-plane beamwidth labels and CST cut naming
2026-10-01 [task 5] State measured and simulated antenna S11 from the Touchstone files
2026-10-01 [task 7] Add stage_gains.py and label every stage gain as VNA or datasheet
    [stage_gains.csv]
2026-10-01 [task 9] Define IP3 input power, tone plan, and tone-level vs VNA gains
2026-10-01 [task 10] State bandpass-filter passband from the datasheet file
2026-10-01 [task 12] State LNA 4 V and ZX60-V63+ 5 V supplies
2026-10-01 [task 16] Correct horn fastening, module mounting, and seam location
2026-10-01 [task 17] Take Lab 02 sheet sizes, hole counts, and hole diameter from the DXFs
2026-10-01 [task 27] Make reference outputs reproducible across platforms and refresh them
    [mergen21_data_manifest.csv, mergen21_hi_line_parameters.csv, mergen21_hi_measurements.csv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]
2026-10-08 [task 8] Friis headline 0.81 dB with VNA stage gains, 0.77 dB datasheet
2026-10-08 [task 9] Note that -15/-18 dBm cascade markers differ from stored traces
2026-10-08 [task 22] Update stale WOLA reference B_eff to 815 Hz
2026-10-08 [task 25] Add motion_shift_kHz to the line parameters; refresh outputs
    [mergen21_data_manifest.csv, mergen21_hi_line_parameters.csv]
2026-10-08 [task 18] Add LDO board Altium sources and un-ignore them (drill file still missing)
    [LDO_RF.PrjPcb, PCB1.PcbDoc, Sheet1.SchDoc]
2026-10-08 [task 18] LDO drill file
2026-10-08 [docs] WOLA taps: GNU Radio needed to rebuild, as-built 824 Hz documented
2026-10-08 [D5] Pluto-terminated band-center captures (re-measured 2026-10-08)
    [captures.csv]
2026-10-14 [v1.1] Fig. 7 script: 0.5 s sweep rows, radiometer line, blocks to 48 s
    Regenerated first_light_and_averaging outputs: panel (b) shows E1, E2, S
    and W with blocks up to 48 s against 1/sqrt(B tau), B = 813.8 Hz; panel (c)
    uses 0.5 s rows (146 s). averaging_noise.csv gains 21 rows; reference copy
    and VERIFICATION.md updated. The script itself is in c70051f.
2026-10-14 [v1.1] WOLA: exact 813.8 Hz radiometric bandwidth and the correct fix
    As built B_rad = 813.8 Hz (exact; the 824 Hz was one Monte Carlo draw,
    822 +/- 20 over seeds 1-20). Resizing alone gives 518.7 Hz with gaps
    between channels; the correct design (16 384 taps, 500 Hz cutoff) gives
    962.6 Hz, so the as-built window needs 1.18x the integration time. The
    "spectral purity, not sensitivity" statements are withdrawn.
2026-10-14 [v1.1] Costs aligned with the paper (about $804, 2026)
    docs/bom.md keeps part numbers, descriptions and distributor notes; exact
    per-item prices, TRY columns and exchange-rate notes are removed. Category
    costs and the total match Table III of the IEEE AP Magazine article:
    horn about $175 (estimated replacement cost; prototype provided in kind),
    RF amplifiers and filter about $344, ADALM-Pluto about $230, regulator PCB
    about $38, cables about $17, total about $804.
2026-10-14 [v1.1] Cable loss is measured; status wording matches what was measured
    The 0.6 dB +/- 0.2 dB output-cable loss is the measured 0.61 dB reference-path
    loss of the IP3 setup (same cable), not re-measured during the NF test. NF
    README states what cable_loss.DAT and cable_loss.PNG show. Hardware status
    says what was characterized (horn S11, receiver gain/NF/OIP3; pattern
    simulated only); the sweep is a qualitative waterfall only. Manifest hash of
    the NF README refreshed in outputs and reference_outputs.
2026-10-14 [v1.1] Lab manual, antenna notes, missing-items list
    Lab 02 B3: LNA output 4.0 V, amplifier output 5.0 V (ZX60-P162LN+ runs at
    4 V). Antenna measurement log notes the unintended 1.53-1.54 GHz resonance
    of folders 1-4 and the shop's 90-degree flare-wall bends. MISSING_FROM_RELEASE
    section 1 points to band_center_tests/ (recorded 2026-10-08).
